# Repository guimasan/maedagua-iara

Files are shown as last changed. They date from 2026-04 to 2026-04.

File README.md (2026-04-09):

# IARA V1 — Monitoramento de Qualidade da Água (Arduino Uno)

Projeto para aquisição de dados de **temperatura** e **TDS/condutividade estimada**, com transmissão serial, painel local e página pública para visualização em tempo real.

## Visão geral

O IARA V1 realiza:

- leitura de temperatura com **DS18B20**
- leitura analógica de **TDS** em `A1`
- exibição local em **OLED SSD1306 I2C (128x64)**
- envio contínuo de telemetria via **USB Serial**

O repositório inclui firmware, backend de painel e dashboard web para uso local e publicação.

## Estrutura do repositório

- `firmware/iara_arduino_uno_v1.ino` — firmware do Arduino Uno
- `iara_iot_server/` — backend + dashboards locais
- `docs/index.html` — dashboard público (GitHub Pages)
- `cad/caixa_iara_v1.scad` — caixa 3D paramétrica (base + tampa)
- `docs/USO_RAPIDO.md` — guia curto de operação
- `tools/calibrar_tds.py` — calibração rápida via serial
- `tools/diagnostico_leituras.py` — diagnóstico comparativo de modos

## Arquitetura de dados

1. O Arduino coleta dados dos sensores.
2. A telemetria é enviada pela serial (`115200`).
3. O bridge (`iara_iot_server/bridge_arduino.py`) converte e publica para a API.
4. Dashboards consomem API/WS para visualização em tempo real e histórico.

Exemplo de payload serial:

```text
DEVICE=iara-uno-0001;SEQ=1;TS_MS=1034;TEMP_C=25.19;TDS_PPM=131;TDS_ADC=287;TDS_V=1.404;TEMP_OK=1;TDS_OK=1;FW=1.0.0
```

## Equipamentos e sensores utilizados

- **Microcontrolador:** Arduino Uno (ATmega328P)
- **Temperatura:** DS18B20 (OneWire)
- **TDS/EC:** módulo TDS analógico compatível com entrada ADC do Uno
- **Display:** OLED SSD1306 I2C 128x64 (`0x3C`)
- **Conexão host:** USB serial

## Ligações elétricas (padrão do projeto)

- **DS18B20:** `D3`, `5V`, `GND`
- **TDS analógico:** `A1`, `5V`, `GND`
- **OLED SSD1306:** `SDA(A4)`, `SCL(A5)`, `5V`, `GND`

## Medidas, faixas e interpretação

### Temperatura (DS18B20)

- resolução configurável pelo sensor: 9–12 bits
- precisão típica de referência: aproximadamente $\pm 0.5\,^{\circ}C$ na faixa central de operação (ver datasheet)
- saída no projeto: `TEMP_C`

### TDS/EC (módulo analógico)

- leitura bruta no ADC de 10 bits do Uno (`0..1023`): `TDS_ADC`
- tensão estimada: `TDS_V`
- concentração estimada: `TDS_PPM`
- valor bruto antes de ganho de calibração: `TDS_RAW_PPM`

> Observação: TDS depende de temperatura, tipo de sonda, circuito e solução de referência. Tratar os valores como **medição estimada**, com calibração periódica.

## Calibração TDS

Campos publicados:

- `CAL` — estado da calibração
- `CAL_GAIN` — ganho aplicado
- `TDS_RAW_PPM` — base sem ganho

Estados de `CAL`:

- `0`: idle
- `1`: aguardando referência
- `2`: aplicado e não salvo
- `3`: salvo em EEPROM

Comandos serial:

- `CAL=ON`
- `CAL=APPLY:<ppm>`
- `CAL=SAVE`
- `CAL=RESET`
- `CAL=OFF`
- `CAL?`

Referência comum de condutividade:

- solução: **1413 µS/cm**
- escala 500: $ppm = EC \times 0.5$
- resultado: $1413 \times 0.5 = 706.5\,ppm$

Aplicação típica: `CAL=APPLY:706.5` seguido de `CAL=SAVE`.

## Modos de diagnóstico de leitura

Comandos para avaliar impacto de OLED e sequência de amostragem:

- `MODE=0` normal
- `MODE=1` pausa OLED durante leitura
- `MODE=2` OLED desligada durante leitura
- `MODE=3` OLED sempre desligada
- `MODE=4` leitura alternada por sensor
- consulta: `MODE?` ou `STATUS`

## Bibliotecas Arduino

- `OneWire`
- `DallasTemperature`
- `Adafruit GFX Library`
- `Adafruit SSD1306`

## Operação rápida

1. Gravar `firmware/iara_arduino_uno_v1.ino` no Arduino Uno.
2. Abrir monitor serial em `115200`.
3. Validar chegada de telemetria.
4. Opcional: executar scripts em `tools/` para diagnóstico/calibração.
5. Subir backend em `iara_iot_server` para dashboard local e integração web.

## Dashboard público (GitHub Pages)

`docs/index.html` fornece:

- visualização em tempo real
- histórico cronológico
- detecção automática de variáveis
- seleção de endpoint da API

Para publicar:

1. Ativar GitHub Pages apontando para `main/docs`.
2. Abrir a página publicada.
3. Configurar a URL da API (preferencialmente HTTPS).

## Boas práticas de medição

- Aguarde estabilização térmica da amostra antes de registrar.
- Evite encostar a sonda nas paredes do recipiente.
- Faça agitação leve e padronizada da amostra.
- Registre temperatura junto com TDS para comparação entre coletas.
- Recalibre periodicamente com solução padrão conhecida.

## Referências técnicas

- Arduino Uno Rev3: https://docs.arduino.cc/hardware/uno-rev3
- ATmega328P (microcontrolador do Uno): https://www.microchip.com/en-us/product/ATmega328P
- DS18B20 (Maxim/Analog): https://www.analog.com/en/products/ds18b20.html
- Biblioteca DallasTemperature: https://github.com/milesburton/Arduino-Temperature-Control-Library
- Biblioteca OneWire (Paul Stoffregen): https://github.com/PaulStoffregen/OneWire
- Adafruit SSD1306: https://github.com/adafruit/Adafruit_SSD1306
- Adafruit GFX: https://github.com/adafruit/Adafruit-GFX-Library

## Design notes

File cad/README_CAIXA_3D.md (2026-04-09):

# Caixa 3D — IARA V1

Este diretório contém um modelo paramétrico em OpenSCAD para a caixa do sistema IARA V1.

## Arquivo

- `caixa_iara_v1.scad`
- `caixa_iara_v1_ondas.scad` (versão alternativa estilizada)

## Arquivos prontos para impressão

Já renderizados neste projeto:

- `cad/stl/caixa_iara_v1_base.stl`
- `cad/stl/caixa_iara_v1_tampa.stl`
- `cad/stl/caixa_iara_v1_ondas_base.stl`
- `cad/stl/caixa_iara_v1_ondas_tampa.stl`

Esses arquivos podem ser importados direto no slicer da sua impressora.

## Versão alternativa estilizada (tema água)

A versão `caixa_iara_v1_ondas.scad` foi desenhada com:

- forma orgânica inspirada em pedra/onda (menos “caixa retangular”)
- tampa com ranhuras decorativas em ondas
- disposição interna para Arduino Uno + TDS + OLED 0.96"
- berço interno para bateria Li-ion `18650`
- saídas dos sensores na lateral direita
- recorte para porta de carga da bateria na lateral traseira

Para essa versão:

- `part = "base"` exporta a base
- `part = "lid"` exporta a tampa
- `show_layout_helpers = true` mostra guias de layout no preview
- `explode_view = true` separa base e tampa no preview
- `style_strength` controla intensidade do relevo das ondas

## Componentes previstos

- Arduino Uno
- Módulo TDS Keyestudio v1.0 (dimensões aproximadas)
- OLED 0.96" I2C
- Saída lateral para cabo do TDS
- Saída lateral para cabo do sensor de temperatura
- Recortes para USB-B e jack DC do Uno

## Saída do display (OLED) — revisão aplicada

A janela do display fica na **tampa superior** e agora é totalmente ajustável por parâmetros:

- `oled_margin_top` → distância da borda superior da tampa até o centro da janela
- `oled_offset_x` → deslocamento horizontal da janela

Também foram incluídos:

- postes internos para fixação do OLED (`lid_oled_posts`)
- canal para passagem do cabo do OLED (`oled_cable_notch_*`)

Se quiser mover a janela para alinhar exatamente ao seu módulo, ajuste esses dois parâmetros e gere apenas a tampa (`part = "lid"`) para teste rápido.

## Saídas dos cabos dos sensores (TDS e temperatura)

As saídas ficam na **lateral direita da base**.

Dimensões aplicadas no modelo:

- TDS (conector): retangular `5 x 7 mm` + folga
- Temperatura (cabo): circular `4 mm` + folga

Para visualizar facilmente no OpenSCAD, use:

- `part = "base"` ou `part = "assembled"`
- `show_cable_helpers = true`

Com isso, o modelo mostra guias verdes transparentes indicando o caminho dos furos. Essas guias são somente preview e **não entram no STL**.

## Como gerar STL

No OpenSCAD:

1. Abra `caixa_iara_v1.scad`
2. Ajuste `part` para:
   - `"base"` para exportar a base
   - `"lid"` para exportar a tampa
3. Renderize (`F6`)
4. Exporte STL

## Configuração inicial de impressão (FDM)

- Bico: 0.4 mm
- Altura de camada: 0.2 mm
- Paredes: 3 linhas
- Infill: 20–30%
- Material sugerido:
  - PLA para protótipo rápido
  - PETG para uso em ambiente úmido/externo
- Suportes: normalmente não necessários

## Perfil sugerido — Creality Hi + PETG Premium

Configuração inicial segura para começar (ajuste fino depois do primeiro teste):

- Bico: `0.4 mm`
- Altura de camada: `0.20 mm`
- Largura de linha: `0.42 mm`
- Paredes: `3`
- Top/Bottom: `5` camadas
- Infill: `25%` (Gyroid ou Grid)
- Temperatura do bico:
   - 1ª camada: `245 °C`
   - demais: `240 °C`
- Mesa:
   - 1ª camada: `80 °C`
   - demais: `75 °C`
- Ventoinha:
   - 1ª camada: `0%`
   - demais: `20–35%`
- Velocidade:
   - perímetro externo: `35 mm/s`
   - perímetro interno: `55 mm/s`
   - preenchimento: `70 mm/s`
- Retração (direct drive):
   - distância: `0.8 mm`
   - velocidade: `35 mm/s`
- Brim: `6 mm` (recomendado para PETG)

### Orientação das peças no slicer

- `caixa_iara_v1_base.stl`: imprimir com o fundo plano na mesa.
- `caixa_iara_v1_tampa.stl`: imprimir com a face externa da tampa voltada para a mesa.

### Material

Para PETG Premium, limpar mesa e aplicar adesão leve (cola bastão/spray apropriado) ajuda a evitar excesso de aderência na remoção.

## Parafusos recomendados

- Fixação de placas: parafuso M3 (autoatarraxante leve ou porca M3, conforme ajuste)
- Fechamento da tampa: M3 x 8 a M3 x 12

## Ajustes esperados (importante)

As dimensões do módulo TDS e do OLED podem variar entre lotes/fabricantes. Recomenda-se:

1. Medir sua placa real com paquímetro
2. Ajustar no SCAD os parâmetros:
   - `tds_x`, `tds_y`, `tds_holes`
   - `oled_*` (janela, furos, postes e canal de cabo)
3. Imprimir um teste rápido da tampa para validar a janela do OLED

## Observação

O modelo foi feito para ser fácil de ajustar em campo e prioriza montagem prática.

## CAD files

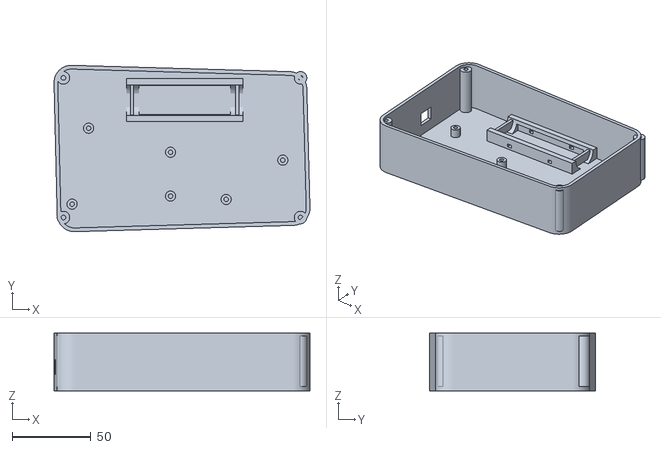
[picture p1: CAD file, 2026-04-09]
cad/stl/caixa_iara_v1_ondas_base.stl
162.8 x 105.8 x 36.8

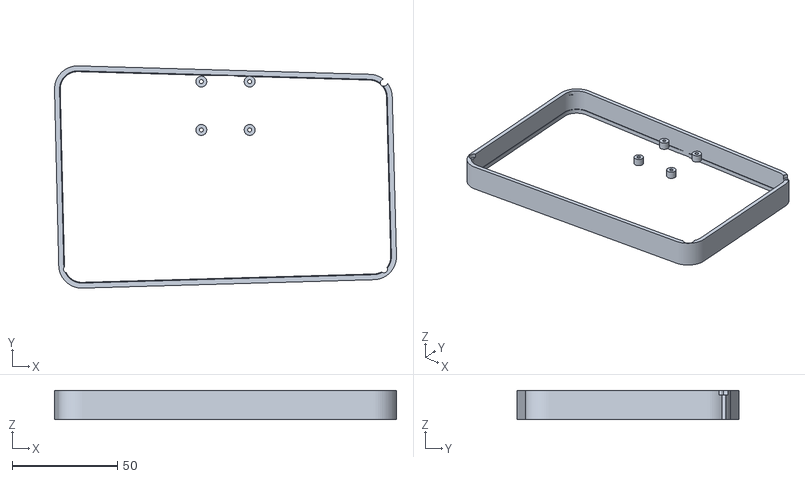
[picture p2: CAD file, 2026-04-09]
cad/stl/caixa_iara_v1_ondas_tampa.stl
162.8 x 105.8 x 14.0

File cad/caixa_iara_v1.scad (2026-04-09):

// IARA V1 - Caixa paramétrica (OpenSCAD)
// Componentes: Arduino Uno, módulo TDS Keyestudio v1.0, OLED 0.96" I2C
// Exportar com: part = "base" ou part = "lid"

$fn = 48;

// =====================
// Seleção de peça
// =====================
part = "assembled"; // "base", "lid", "assembled"

// =====================
// Dimensões gerais (mm)
// =====================
wall = 2.4;
bottom = 2.8;
lid_thickness = 2.4;
clearance = 0.35;
corner_r = 8;

inner_x = 140;
inner_y = 88;
inner_z = 32; // altura útil interna da base

outer_x = inner_x + wall * 2;
outer_y = inner_y + wall * 2;
base_h = bottom + inner_z;
lid_h = 13;

// =====================
// Arduino Uno R3 (aprox.)
// =====================
uno_x = 68.6;
uno_y = 53.4;
uno_h = 14; // folga para componentes + headers
standoff_d = 6.5;
standoff_h = 6;
standoff_hole_d = 2.9; // para parafuso M3 autoatarraxante leve

// Furação aproximada (referência no canto da placa)
uno_holes = [
    [3.5, 2.5],
    [66.1, 7.6],
    [66.1, 35.5],
    [14.0, 50.8]
];

// posição da placa dentro da caixa
uno_pos = [10, 10, bottom];

// recortes laterais para USB-B e jack DC (lado esquerdo da caixa)
usb_cut = [13, 11.5, 9.5]; // x(profundidade), y(largura), z(altura)
usb_cut_pos = [0, uno_pos[1] + 36, 10.5];

jack_cut_d = 11;
jack_cut_pos = [0, uno_pos[1] + 16.5, 11.5];

// =====================
// Módulo TDS Keyestudio v1.0 (aprox.)
// =====================
tds_x = 43;
tds_y = 32;
tds_pos = [86, 12, bottom];
tds_holes = [
    [3.5, 3.5],
    [39.5, 28.5]
];

// =====================
// OLED 0.96" (módulo I2C 4 pinos)
// =====================
oled_board_x = 27.5;
oled_board_y = 27.5;
oled_hole_pitch_x = 23;
oled_hole_pitch_y = 23;
oled_screen_x = 23.5;
oled_screen_y = 13.5;

oled_center = [outer_x / 2, outer_y - 22];

// =====================
// Saídas de cabo
// =====================
// Lado direito da base
cable_tds_d = 6.6;
cable_temp_d = 4.8;

cable_tds_pos = [outer_x, 24, 11.5];
cable_temp_pos = [outer_x, 39, 10.5];

// =====================
// Parafusos da tampa
// =====================
post_d = 8;
post_hole_d = 3.0;
post_core_h = inner_z - 2;

post_xy = [
    [10, 10],
    [outer_x - 10, 10],
    [outer_x - 10, outer_y - 10],
    [10, outer_y - 10]
];

module rounded_box(x, y, z, r) {
    hull() {
        for (ix = [r, x - r])
            for (iy = [r, y - r])
                translate([ix, iy, 0]) cylinder(h = z, r = r);
    }
}

module shell_base() {
    difference() {
        rounded_box(outer_x, outer_y, base_h, corner_r);
        translate([wall, wall, bottom])
            rounded_box(inner_x, inner_y, inner_z + 0.2, max(corner_r - wall, 1));
    }
}

module lid_shell() {
    difference() {
        rounded_box(outer_x, outer_y, lid_h, corner_r);

        // cavidade da tampa
        translate([wall, wall, lid_thickness])
            rounded_box(inner_x, inner_y, lid_h, max(corner_r - wall, 1));

        // aba de encaixe
        translate([wall + clearance, wall + clearance, 0])
            rounded_box(inner_x - 2 * clearance, inner_y - 2 * clearance, 8, max(corner_r - wall - clearance, 1));

        // remover centro da aba
        translate([wall + 2.2, wall + 2.2, 0])
            rounded_box(inner_x - 4.4, inner_y - 4.4, 8.1, max(corner_r - wall - 2.2, 1));
    }
}

module board_standoffs(origin, holes) {
    for (h = holes) {
        translate([origin[0] + h[0], origin[1] + h[1], origin[2]])
            difference() {
                cylinder(h = standoff_h, d = standoff_d);
                translate([0, 0, -0.1]) cylinder(h = standoff_h + 0.2, d = standoff_hole_d);
            }
    }
}

module lid_posts_for_screws() {
    for (p = post_xy) {
        translate([p[0], p[1], bottom])
            difference() {
                cylinder(h = post_core_h, d = post_d);
                translate([0, 0, -0.1]) cylinder(h = post_core_h + 0.2, d = post_hole_d);
            }
    }
}

module cable_holes() {
    // TDS
    translate(cable_tds_pos)
        rotate([0, 90, 0]) cylinder(h = wall + 1.5, d = cable_tds_d);

    // Temperatura
    translate(cable_temp_pos)
        rotate([0, 90, 0]) cylinder(h = wall + 1.5, d = cable_temp_d);
}

module uno_side_ports() {
    // USB-B
    translate([usb_cut_pos[0] - 0.5, usb_cut_pos[1], usb_cut_pos[2]])
        cube([usb_cut[0] + 1, usb_cut[1], usb_cut[2]]);

    // Jack DC
    translate([jack_cut_pos[0] - 0.5, jack_cut_pos[1], jack_cut_pos[2]])
        rotate([0, 90, 0]) cylinder(h = wall + 1.5, d = jack_cut_d);
}

module lid_oled_window_and_holes() {
    // Janela do display
    translate([oled_center[0] - oled_screen_x / 2, oled_center[1] - oled_screen_y / 2, -0.2])
        cube([oled_screen_x, oled_screen_y, lid_thickness + 0.6]);

    // Furos da placa OLED
    for (sx = [-oled_hole_pitch_x / 2, oled_hole_pitch_x / 2])
        for (sy = [-oled_hole_pitch_y / 2, oled_hole_pitch_y / 2])
            translate([oled_center[0] + sx, oled_center[1] + sy, -0.2])
                cylinder(h = lid_thickness + 1.2, d = 2.4);
}

module lid_screw_holes() {
    for (p = post_xy) {
        translate([p[0], p[1], -0.2])
            cylinder(h = lid_h + 0.4, d = 3.4);

        // rebaixo para cabeça do parafuso
        translate([p[0], p[1], lid_h - 2.2])
            cylinder(h = 2.5, d = 6.2);
    }
}

module base_part() {
    difference() {
        shell_base();
        cable_holes();
        uno_side_ports();
    }

    // Standoffs Arduino
    board_standoffs(uno_pos, uno_holes);

    // Standoffs TDS
    board_standoffs(tds_pos, tds_holes);

    // Postes para parafusos da tampa
    lid_posts_for_screws();
}

module lid_part() {
    difference() {
        lid_shell();
        lid_oled_window_and_holes();
        lid_screw_holes();
    }
}

if (part == "base") {
    base_part();
}

if (part == "lid") {
    lid_part();
}

if (part == "assembled") {
    color("#1f2937") base_part();
    translate([0, 0, base_h + 0.2]) color("#334155") lid_part();
}

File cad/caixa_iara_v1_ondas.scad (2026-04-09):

// IARA V1 - Caixa alternativa estilizada (tema água: ondas/rios)
// Componentes: Arduino Uno + TDS Keyestudio + OLED 0.96" + bateria 18650 interna
// Exportar com: part = "base" ou part = "lid"

$fn = 64;

part = "assembled"; // "base", "lid", "assembled"
show_layout_helpers = false; // preview de disposição interna
explode_view = true;         // separa base/tampa no preview para enxergar melhor
explode_gap = 18;            // distância (mm) entre base e tampa no preview
style_strength = 1.0;        // 1.0 = padrão, >1 ondas mais marcadas

// =====================
// Dimensões gerais
// =====================
wall = 2.4;
bottom = 2.8;
lid_thickness = 2.4;
clearance = 0.35;

inner_x = 170;
inner_y = 108;
inner_z = 34;

outer_x = inner_x + wall * 2;
outer_y = inner_y + wall * 2;
base_h = bottom + inner_z;
lid_h = 14;

corner_r = 11;

// =====================
// Furação e parafusos da tampa
// =====================
post_d = 8;
post_hole_d = 3.0;
post_core_h = inner_z - 2;
post_xy = [
    [12, 12],
    [outer_x - 12, 12],
    [outer_x - 12, outer_y - 12],
    [12, outer_y - 12]
];

// =====================
// Arduino Uno
// =====================
uno_pos = [14, 18, bottom];
standoff_d = 6.5;
standoff_h = 6;
standoff_hole_d = 2.9;
uno_holes = [
    [3.5, 2.5],
    [66.1, 7.6],
    [66.1, 35.5],
    [14.0, 50.8]
];

// recortes laterais do Uno (lado esquerdo da caixa)
usb_cut = [13, 11.5, 9.5];
usb_cut_pos = [0, uno_pos[1] + 36, 10.5];
jack_cut_d = 11;
jack_cut_pos = [0, uno_pos[1] + 16.5, 11.5];

// =====================
// TDS Keyestudio v1.0 (aprox.)
// =====================
tds_pos = [112, 20, bottom];
tds_holes = [
    [3.5, 3.5],
    [39.5, 28.5]
];

// =====================
// Bateria 18650 interna
// =====================
bat_d = 18.6 + 0.8;
bat_len = 65 + 1.2;

battery_cradle_pos = [52, 73, bottom + 2.2];
battery_cradle_w = bat_d + 8;
battery_cradle_l = bat_len + 8;
battery_cradle_h = 8.5;

// =====================
// OLED 0.96"
// =====================
oled_hole_pitch_x = 23;
oled_hole_pitch_y = 23;
oled_screen_x = 23.5;
oled_screen_y = 13.5;

oled_margin_top = 23;
oled_offset_x = 0;
oled_center = [outer_x / 2 + oled_offset_x, outer_y - oled_margin_top];

oled_hole_d = 2.4;
oled_post_d = 5.2;
oled_post_h = 4.0;
oled_post_hole_d = 1.9;

oled_cable_notch_w = 8;
oled_cable_notch_h = 4;

// =====================
// Saídas dos sensores
// =====================
cable_fit_clearance = 0.35;

// TDS: conector retangular 5x7 mm
cable_tds_w = 5 + cable_fit_clearance;
cable_tds_h = 7 + cable_fit_clearance;

// Temperatura: cabo 4 mm
cable_temp_d = 4 + cable_fit_clearance;

cable_cut_depth = wall + 2.4;

cable_tds_center_y = 32;
cable_tds_center_z = 12;
cable_tds_pos = [outer_x - cable_cut_depth, cable_tds_center_y - cable_tds_w / 2, cable_tds_center_z - cable_tds_h / 2];

cable_temp_pos = [outer_x - cable_cut_depth, 50, 11];

// recorte opcional para porta de carga da bateria (ex.: TP4056 USB-C/micro)
charge_cut = [11, wall + 2.2, 6.2];
charge_cut_pos = [outer_x / 2 - charge_cut[0] / 2, outer_y - charge_cut[1], 9.5];

echo("OLED center XY:", oled_center);

module riverstone_box(x, y, z, r) {
    hull() {
        translate([r + 8, r + 3, 0]) cylinder(h = z, r = r);
        translate([x - r - 6, r + 7, 0]) cylinder(h = z, r = r);
        translate([x - r - 8, y - r - 8, 0]) cylinder(h = z, r = r);
        translate([r + 6, y - r - 4, 0]) cylinder(h = z, r = r);
    }
}

module shell_base() {
    difference() {
        riverstone_box(outer_x, outer_y, base_h, corner_r);
        translate([wall, wall, bottom])
            riverstone_box(inner_x, inner_y, inner_z + 0.2, max(corner_r - wall, 2));
    }
}

module shell_lid() {
    difference() {
        riverstone_box(outer_x, outer_y, lid_h, corner_r);

        // cavidade interna da tampa
        translate([wall, wall, lid_thickness])
            riverstone_box(inner_x, inner_y, lid_h, max(corner_r - wall, 2));

        // aba de encaixe
        translate([wall + clearance, wall + clearance, 0])
            riverstone_box(inner_x - 2 * clearance, inner_y - 2 * clearance, 8.2, max(corner_r - wall - clearance, 2));

        // alívio do centro da aba
        translate([wall + 2.2, wall + 2.2, 0])
            riverstone_box(inner_x - 4.4, inner_y - 4.4, 8.4, max(corner_r - wall - 2.2, 2));
    }
}

module board_standoffs(origin, holes) {
    for (h = holes) {
        translate([origin[0] + h[0], origin[1] + h[1], origin[2]])
            difference() {
                cylinder(h = standoff_h, d = standoff_d);
                translate([0, 0, -0.1]) cylinder(h = standoff_h + 0.2, d = standoff_hole_d);
            }
    }
}

module lid_posts_for_screws() {
    for (p = post_xy) {
        translate([p[0], p[1], bottom])
            difference() {
                cylinder(h = post_core_h, d = post_d);
                translate([0, 0, -0.1]) cylinder(h = post_core_h + 0.2, d = post_hole_d);
            }
    }
}

module sensor_cable_holes() {
    // TDS retangular
    translate(cable_tds_pos)
        cube([cable_cut_depth, cable_tds_w, cable_tds_h]);

    // temperatura circular
    translate(cable_temp_pos)
        rotate([0, 90, 0]) cylinder(h = cable_cut_depth, d = cable_temp_d);
}

module uno_side_ports() {
    // USB-B
    translate([usb_cut_pos[0] - 0.5, usb_cut_pos[1], usb_cut_pos[2]])
        cube([usb_cut[0] + 1, usb_cut[1], usb_cut[2]]);

    // Jack DC
    translate([jack_cut_pos[0] - 0.5, jack_cut_pos[1], jack_cut_pos[2]])
        rotate([0, 90, 0]) cylinder(h = wall + 1.5, d = jack_cut_d);
}

module battery_charge_cutout() {
    translate(charge_cut_pos)
        cube(charge_cut);
}

module battery_cradle() {
    translate(battery_cradle_pos)
        difference() {
            cube([battery_cradle_l, battery_cradle_w, battery_cradle_h]);

            // canal semicircular para 18650
            translate([battery_cradle_l / 2, battery_cradle_w / 2, battery_cradle_h + 0.2])
                rotate([0, 90, 0])
                    cylinder(h = battery_cradle_l + 0.4, r = bat_d / 2, center = true);

            // janela inferior para reduzir material e facilitar encaixe
            translate([8, 3, -0.1])
                cube([battery_cradle_l - 16, battery_cradle_w - 6, battery_cradle_h - 2.6]);

            // slots de abraçadeira (zip tie)
            translate([18, -0.1, 1.8]) cube([3.2, battery_cradle_w + 0.2, 2.2]);
            translate([battery_cradle_l - 21.2, -0.1, 1.8]) cube([3.2, battery_cradle_w + 0.2, 2.2]);
        }
}

module battery_end_stops() {
    // batentes para a célula não deslizar
    translate([battery_cradle_pos[0] + 2.5, battery_cradle_pos[1] + 2.2, battery_cradle_pos[2] + 1.4])
        cube([2.2, battery_cradle_w - 4.4, 6]);
    translate([battery_cradle_pos[0] + battery_cradle_l - 4.7, battery_cradle_pos[1] + 2.2, battery_cradle_pos[2] + 1.4])
        cube([2.2, battery_cradle_w - 4.4, 6]);
}

module lid_oled_window_and_holes() {
    // janela do display
    translate([oled_center[0] - oled_screen_x / 2, oled_center[1] - oled_screen_y / 2, -0.2])
        cube([oled_screen_x, oled_screen_y, lid_thickness + 0.8]);

    // furos da placa OLED
    for (sx = [-oled_hole_pitch_x / 2, oled_hole_pitch_x / 2])
        for (sy = [-oled_hole_pitch_y / 2, oled_hole_pitch_y / 2])
            translate([oled_center[0] + sx, oled_center[1] + sy, -0.2])
                cylinder(h = lid_thickness + 1.3, d = oled_hole_d);

    // canal para fios do OLED
    translate([oled_center[0] - oled_cable_notch_w / 2, oled_center[1] + oled_hole_pitch_y / 2 - 1, -0.2])
        cube([oled_cable_notch_w, oled_cable_notch_h, lid_thickness + 0.8]);
}

module lid_oled_posts() {
    for (sx = [-oled_hole_pitch_x / 2, oled_hole_pitch_x / 2])
        for (sy = [-oled_hole_pitch_y / 2, oled_hole_pitch_y / 2])
            translate([oled_center[0] + sx, oled_center[1] + sy, lid_thickness])
                difference() {
                    cylinder(h = oled_post_h, d = oled_post_d);
                    translate([0, 0, -0.1]) cylinder(h = oled_post_h + 0.2, d = oled_post_hole_d);
                }
}

module lid_screw_holes() {
    for (p = post_xy) {
        translate([p[0], p[1], -0.2])
            cylinder(h = lid_h + 0.4, d = 3.4);
        translate([p[0], p[1], lid_h - 2.2])
            cylinder(h = 2.5, d = 6.2);
    }
}

// ranhuras decorativas em forma de onda (relevo negativo)
module wave_slot(y0, amp, phase, depth = 2.0, radius = 2.0) {
    for (x = [14:10:outer_x - 24]) {
        x2 = x + 10;
        y1 = y0 + amp * sin((x + phase) * 2.6);
        y2 = y0 + amp * sin((x2 + phase) * 2.6);
        hull() {
            translate([x, y1, lid_h - depth]) cylinder(h = depth + 0.35, r = radius);
            translate([x2, y2, lid_h - depth]) cylinder(h = depth + 0.35, r = radius);
        }
    }
}
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

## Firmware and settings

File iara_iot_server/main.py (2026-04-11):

from __future__ import annotations

import asyncio
import json
import time
from collections import defaultdict, deque
from pathlib import Path
from typing import Any

from fastapi import FastAPI, Request, WebSocket, WebSocketDisconnect
from fastapi.middleware.cors import CORSMiddleware
from fastapi.responses import FileResponse, JSONResponse
from fastapi.staticfiles import StaticFiles

BASE_DIR = Path(__file__).resolve().parent
STATIC_DIR = BASE_DIR / "static"

app = FastAPI(title="Painel IoT Realtime")
app.add_middleware(
    CORSMiddleware,
    allow_origins=["*"],
    allow_credentials=False,
    allow_methods=["*"],
    allow_headers=["*"],
)
app.mount("/static", StaticFiles(directory=str(STATIC_DIR)), name="static")

devices: dict[str, dict[str, Any]] = {
    "esp32c6": {
        "device": "esp32c6",
        "device_public_id": "ESP32C6",
        "chip": "ESP32-C6",
        "counter": 0,
        "value": 0.0,
        "temp_c": None,
        "tds_ppm": 0.0,
        "uptime_ms": 0,
        "project": "maedagua",
        "protocol": "iara.v1.telemetry",
        "privacy": "impersonal",
        "hub": {"queue_size": 0, "last_ack": {}},
        "ts": time.time(),
    }
}
logs_by_device: dict[str, deque[dict[str, Any]]] = defaultdict(lambda: deque(maxlen=500))
commands_by_device: dict[str, list[dict[str, Any]]] = defaultdict(list)
last_ack_by_device: dict[str, dict[str, Any]] = defaultdict(dict)
view_clients: set[WebSocket] = set()
clients_lock = asyncio.Lock()
next_command_id = 1


def _default_device_state(device: str) -> dict[str, Any]:
    return {
        "device": device,
        "device_public_id": device.upper(),
        "chip": "unknown",
        "counter": 0,
        "value": 0.0,
        "temp_c": None,
        "tds_ppm": 0.0,
        "uptime_ms": 0,
        "project": "maedagua",
        "protocol": "iara.v1.telemetry",
        "privacy": "impersonal",
        "hub": {
            "queue_size": 0,
            "last_ack": {},
        },
        "ts": time.time(),
    }


@app.get("/")
async def root() -> FileResponse:
    return FileResponse(str(STATIC_DIR / "index.html"))


@app.get("/device/{device_id}")
async def device_dashboard(device_id: str) -> FileResponse:
    return FileResponse(str(STATIC_DIR / "device.html"))


async def _broadcast_to_viewers(payload: dict[str, Any]) -> None:
    text = json.dumps(payload)

    async with clients_lock:
        clients = list(view_clients)

    stale: list[WebSocket] = []
    for ws in clients:
        try:
            await ws.send_text(text)
        except Exception:
            stale.append(ws)

    if stale:
        async with clients_lock:
            for ws in stale:
                view_clients.discard(ws)


def _normalize_device(raw: Any) -> str:
    if isinstance(raw, str) and raw.strip():
        return raw.strip().lower()
    return "esp32c6"


def _append_log(device: str, event: str, payload: dict[str, Any]) -> None:
    logs_by_device[device].append(
        {
            "ts": time.time(),
            "event": event,
            "payload": payload,
        }
    )


def _hub_snapshot(device: str) -> dict[str, Any]:
    queue = commands_by_device.get(device, [])
    pending = sum(1 for item in queue if item.get("status") in {"pending", "sent"})
    return {
        "queue_size": pending,
        "last_ack": last_ack_by_device.get(device, {}),
    }


def _ensure_device(device: str) -> dict[str, Any]:
    if device not in devices:
        devices[device] = _default_device_state(device)
    return devices[device]


def _refresh_hub_for_device(device: str) -> None:
    state = _ensure_device(device)
    state["hub"] = _hub_snapshot(device)


@app.post("/api/telemetry")
async def telemetry(request: Request) -> JSONResponse:
    payload = await request.json()
    if not isinstance(payload, dict):
        return JSONResponse({"ok": False, "error": "JSON inválido"}, status_code=400)

    device = _normalize_device(payload.get("device"))
    payload["device"] = device
    payload.setdefault("ts", time.time())
    payload.setdefault("protocol", "iara.v1.telemetry")
    payload.setdefault("project", "maedagua")
    payload.setdefault("privacy", "impersonal")
    payload.setdefault("device_public_id", device.upper())
    payload["hub"] = _hub_snapshot(device)
    devices[device] = payload
    _append_log(device, "telemetry", payload)

    await _broadcast_to_viewers(payload)

    return JSONResponse({"ok": True})


@app.get("/api/telemetry/all")
async def telemetry_all() -> JSONResponse:
    return JSONResponse({"ok": True, "devices": devices})


@app.get("/api/devices")
async def list_devices() -> JSONResponse:
    rows: list[dict[str, Any]] = []
    now = time.time()
    for device, data in devices.items():
        ts = float(data.get("ts", 0) or 0)
        rows.append(
            {
                "device": device,
                "device_public_id": data.get("device_public_id", device.upper()),
                "chip": data.get("chip", "unknown"),
                "model": data.get("model", "unknown"),
                "project": data.get("project", "maedagua"),
                "protocol": data.get("protocol", "iara.v1.telemetry"),
                "last_seen_s": max(0, int(now - ts)) if ts else None,
                "status": "online" if ts and now - ts < 15 else "offline",
                "temp_c": data.get("temp_c"),
                "tds_ppm": data.get("tds_ppm", data.get("value")),
            }
        )

    rows.sort(key=lambda d: d["device"])
    return JSONResponse({"ok": True, "devices": rows})


@app.get("/api/device/{device_id}/state")
async def device_state(device_id: str) -> JSONResponse:
    device = _normalize_device(device_id)
    if device not in devices:
        return JSONResponse({"ok": False, "error": "Device não encontrado"}, status_code=404)

    return JSONResponse(
        {
            "ok": True,
            "device": devices[device],
            "logs": list(logs_by_device[device])[-120:],
        }
    )


@app.get("/api/device/{device_id}/logs")
async def device_logs_route(device_id: str, limit: int = 120) -> JSONResponse:
    device = _normalize_device(device_id)
    if device not in devices:
        return JSONResponse({"ok": False, "error": "Device não encontrado"}, status_code=404)

    safe_limit = max(1, min(limit, 500))
    return JSONResponse({"ok": True, "logs": list(logs_by_device[device])[-safe_limit:]})


@app.post("/api/ui/command")
async def queue_command(request: Request) -> JSONResponse:
    global next_command_id

    payload = await request.json()
    if not isinstance(payload, dict):
        return JSONResponse({"ok": False, "error": "JSON inválido"}, status_code=400)

    action = payload.get("action")
    if not isinstance(action, str) or not action.strip():
        return JSONResponse({"ok": False, "error": "Campo action é obrigatório"}, status_code=400)

    device = _normalize_device(payload.get("device"))
    command = {
        "id": next_command_id,
        "device": device,
        "action": action.strip(),
        "value": payload.get("value"),
        "status": "pending",
        "created_at": time.time(),
    }
    next_command_id += 1

    queue = commands_by_device[device]
    queue.append(command)
    if len(queue) > 120:
        commands_by_device[device] = queue[-120:]

    _refresh_hub_for_device(device)
    _append_log(device, "command_queued", command)
    await _broadcast_to_viewers(devices[device])

    return JSONResponse({"ok": True, "command": command})


@app.get("/api/device/command")
async def pull_command(device: str = "esp32c6") -> JSONResponse:
    normalized = _normalize_device(device)
    queue = commands_by_device[normalized]

    for cmd in queue:
        if cmd.get("status") in {"pending", "sent"}:
            cmd["status"] = "sent"
            cmd["sent_at"] = time.time()
            return JSONResponse({"ok": True, "command": cmd})

    return JSONResponse({"ok": True, "command": None})


@app.post("/api/device/ack")
async def ack_command(request: Request) -> JSONResponse:
    payload = await request.json()
    if not isinstance(payload, dict):
        return JSONResponse({"ok": False, "error": "JSON inválido"}, status_code=400)

    device = _normalize_device(payload.get("device"))
    command_id = payload.get("command_id")
    status = payload.get("status", "ok")
    message = payload.get("message", "")

    queue = commands_by_device[device]
    target: dict[str, Any] | None = None
    for cmd in queue:
        if cmd.get("id") == command_id:
            target = cmd
            break

    if target is None:
        return JSONResponse({"ok": False, "error": "Comando não encontrado"}, status_code=404)

    target["status"] = "ack"
    target["ack_status"] = status
    target["ack_message"] = message
    target["ack_at"] = time.time()

    if len(queue) > 60:
        commands_by_device[device] = queue[-60:]

    last_ack_by_device[device] = {
        "command_id": command_id,
        "status": status,
        "message": message,
        "ts": time.time(),
    }

    _refresh_hub_for_device(device)
    _append_log(
        device,
        "command_ack",
        {
            "command_id": command_id,
            "status": status,
            "message": message,
        },
    )
    await _broadcast_to_viewers(devices[device])

    return JSONResponse({"ok": True})


@app.websocket("/ws/view")
async def ws_view(websocket: WebSocket) -> None:
    await websocket.accept()

    async with clients_lock:
        view_clients.add(websocket)

    try:
        if devices:
            newest = max(devices.values(), key=lambda d: float(d.get("ts", 0) or 0))
            await websocket.send_json(newest)
        else:
            await websocket.send_json(_default_device_state("esp32c6"))

        while True:
            await websocket.receive_text()
    except WebSocketDisconnect:
        pass
    finally:
        async with clients_lock:
            view_clients.discard(websocket)


if __name__ == "__main__":
    import uvicorn

    uvicorn.run("main:app", host="0.0.0.0", port=8000, reload=True)

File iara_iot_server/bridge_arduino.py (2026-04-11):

from __future__ import annotations

import json
import os
import time
from pathlib import Path
from typing import Any
from urllib import parse, request

import serial


def load_env_file(path: Path) -> None:
    if not path.exists():
        return

    for raw_line in path.read_text(encoding="utf-8").splitlines():
        line = raw_line.strip()
        if not line or line.startswith("#") or "=" not in line:
            continue
        key, value = line.split("=", 1)
        key = key.strip()
        value = value.strip().strip('"').strip("'")
        if key and key not in os.environ:
            os.environ[key] = value


def _coerce(raw: str) -> Any:
    value = raw.strip()
    if value.upper() == "NAN":
        return None
    if value.lower() in {"true", "false"}:
        return value.lower() == "true"
    try:
        if any(ch in value for ch in [".", "e", "E"]):
            return float(value)
        return int(value)
    except Exception:
        return value


def _parse_kv_line(line: str) -> dict[str, Any]:
    out: dict[str, Any] = {}
    for part in [p.strip() for p in line.split(";") if p.strip()]:
        if "=" not in part:
            continue
        k, v = part.split("=", 1)
        out[k.strip().lower()] = _coerce(v)
    return out


def parse_uno_line(line: str) -> dict[str, Any] | None:
    parts = [p.strip() for p in line.split(";") if p.strip()]
    if not parts:
        return None

    header = parts[0].upper()

    if header == "IARA_HELLO":
        kv = _parse_kv_line(";".join(parts[1:]))
        device_public_id = kv.get("device_public_id")
        if not isinstance(device_public_id, str) or not device_public_id:
            return None

        modules_raw = kv.get("modules", "")
        modules = [m.strip() for m in str(modules_raw).split(",") if m.strip()]

        return {
            "kind": "hello",
            "project": str(kv.get("project", "maedagua")),
            "protocol": str(kv.get("protocol", "iara.v1")),
            "device_public_id": device_public_id,
            "model": str(kv.get("model", "iara_v1_uno")),
            "fw": str(kv.get("fw", "1.0.0")),
            "modules": modules,
        }

    if header == "IARA_TLM":
        kv = _parse_kv_line(";".join(parts[1:]))
        device_public_id = kv.get("device_public_id")
        if not isinstance(device_public_id, str) or not device_public_id:
            return None

        temp_c = kv.get("temp_c") if isinstance(kv.get("temp_c"), (int, float)) or kv.get("temp_c") is None else None
        tds_ppm = float(kv.get("tds_ppm", 0) or 0)
        a1_v = float(kv.get("a1_v", 0) or 0)

        return {
            "kind": "telemetry",
            "project": str(kv.get("project", "maedagua")),
            "protocol": str(kv.get("protocol", "iara.v1")),
            "device_public_id": device_public_id,
            "temp_c": temp_c,
            "tds_ppm": tds_ppm,
            "a1_v": a1_v,
            "ts_ms": int(kv.get("ts_ms", 0) or 0),
            "fields": kv,
        }

    kv = _parse_kv_line(line)
    if "temp_c" not in kv and "tds_ppm" not in kv and "device" not in kv:
        return None

    device_public_id = str(kv.get("device", "iara-uno-0001"))
    temp_raw = kv.get("temp_c")
    temp_c = temp_raw if isinstance(temp_raw, (int, float)) or temp_raw is None else None
    tds_ppm = float(kv.get("tds_ppm", 0) or 0)
    a1_v = float(kv.get("a1_v", kv.get("tds_v", 0)) or 0)

    return {
        "kind": "telemetry",
        "project": str(kv.get("project", "maedagua")),
        "protocol": str(kv.get("protocol", "iara.v1")),
        "device_public_id": device_public_id,
        "temp_c": temp_c,
        "tds_ppm": tds_ppm,
        "a1_v": a1_v,
        "fields": kv,
    }


def post_payload(url: str, payload: dict[str, Any]) -> int:
    body = json.dumps(payload).encode("utf-8")
    req = request.Request(
        url,
        data=body,
        headers={"Content-Type": "application/json"},
        method="POST",
    )
    with request.urlopen(req, timeout=4) as resp:
        return resp.status


def pull_command(base_url: str, device: str) -> dict[str, Any] | None:
    url = f"{base_url.rstrip('/')}/api/device/command?{parse.urlencode({'device': device.lower()})}"
    with request.urlopen(url, timeout=4) as resp:
        data = json.loads(resp.read().decode("utf-8"))
    if not data.get("ok"):
        return None
    cmd = data.get("command")
    if not isinstance(cmd, dict):
        return None
    return cmd


def ack_command(base_url: str, device: str, command_id: int, status: str, message: str) -> None:
    payload = {
        "device": device.lower(),
        "command_id": command_id,
        "status": status,
        "message": message,
    }
    body = json.dumps(payload).encode("utf-8")
    req = request.Request(
        f"{base_url.rstrip('/')}/api/device/ack",
        data=body,
        headers={"Content-Type": "application/json"},
        method="POST",
    )
    with request.urlopen(req, timeout=4):
        pass


def map_action_to_serial(action: str, value: Any, ec_to_ppm_factor: float) -> str | None:
    action = (action or "").strip().lower()

    if action == "serial_cmd" and isinstance(value, str) and value.strip():
        return value.strip()
    if action == "cal_on":
        return "CAL=ON"
    if action == "cal_off":
        return "CAL=OFF"
    if action == "cal_save":
        return "CAL=SAVE"
    if action == "cal_reset":
        return "CAL=RESET"
    if action == "cal_status":
        return "CAL?"
    if action == "set_read_mode":
        return f"MODE={int(value)}"
    if action == "set_display_mode":
        return f"DISP={int(value)}"
    if action == "cal_apply_ppm":
        try:
            ppm = float(value)
            return f"CAL=APPLY:{ppm:.2f}"
        except Exception:
            return None
    if action == "cal_apply_uscm":
        try:
            us_cm = float(value["us_cm"] if isinstance(value, dict) else value)
            factor = float(value.get("factor", ec_to_ppm_factor)) if isinstance(value, dict) else ec_to_ppm_factor
            ppm = us_cm * factor
            return f"CAL=APPLY:{ppm:.2f}"
        except Exception:
            return None
    if action == "cal_apply_1413":
        ppm = 1413.0 * ec_to_ppm_factor
        return f"CAL=APPLY:{ppm:.2f}"

    return None


def telemetry_base_url(full_telemetry_url: str) -> str:
    marker = "/api/telemetry"
    if marker in full_telemetry_url:
        return full_telemetry_url.split(marker, 1)[0]
    return full_telemetry_url.rstrip("/")
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

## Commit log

2026-04-09 chore: renomear projeto para IARA V1
2026-04-09 refactor: renomear painel para iara_iot_server
2026-04-09 feat(cad): adicionar caixa 3D paramétrica para IARA V1
    [caixa_iara_v1.scad]
2026-04-09 feat(cad): adicionar versão estilizada tema água com berço 18650
    [caixa_iara_v1_ondas.scad, caixa_iara_v1_ondas_base.stl, caixa_iara_v1_ondas_tampa.stl]
2026-04-09 feat(cad): destacar visual da versão ondas com preview explodido
    [caixa_iara_v1_ondas.scad, caixa_iara_v1_ondas_base.stl, caixa_iara_v1_ondas_tampa.stl]
